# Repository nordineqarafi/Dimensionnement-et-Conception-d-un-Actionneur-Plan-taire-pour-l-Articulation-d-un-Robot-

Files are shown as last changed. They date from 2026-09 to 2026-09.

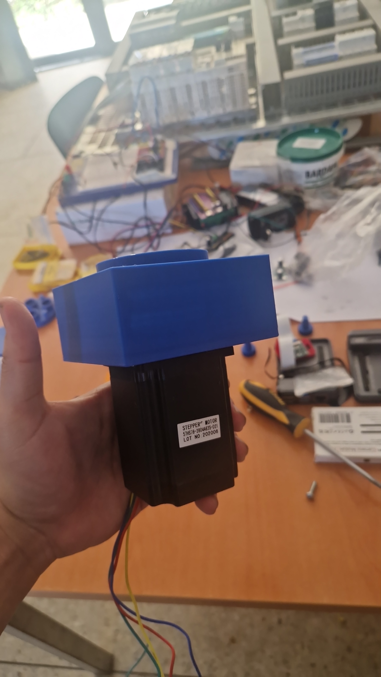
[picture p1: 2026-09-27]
1000091351.jpg

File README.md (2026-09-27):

# Dimensionnement et conception d’un actionneur planétaire pour un robot d’inspection TGV

**Noureddine Qarafi · Qassab Abderrahmane · Aymane El Haoudar**  
**ENSAM Meknès · Filière GEE-MCI · Année universitaire 2025/2026**

Projet de conception mécatronique consacré au **dimensionnement d’un actionneur planétaire** destiné aux articulations d’un bras robotisé d’inspection sous caisse de train à grande vitesse.

Le système étudié associe un **moteur pas à pas NEMA 23**, un **réducteur planétaire**, un **driver TB6600** et une **commande Arduino Mega 2560**. Le travail couvre le choix technologique, le dimensionnement mécanique du réducteur, les vérifications de résistance, l’étude de variantes d’intégration et la validation de la chaîne de commande.

## Contexte du projet

Le projet s’inscrit dans le développement du robot **InspecTrain**, destiné à automatiser l’inspection visuelle sous caisse des rames à grande vitesse.

Le robot doit évoluer dans une fosse d’inspection ferroviaire et orienter une caméra vers différentes zones du bogie, des essieux, du système de freinage, des canalisations et des câblages.

Le bras d’inspection comporte **trois degrés de liberté** :

- **Articulation 1 — rotation azimutale** : rotation panoramique du bras.
- **Articulation 2 — coude bas** : élévation du premier segment du bras.
- **Articulation 3 — coude haut** : orientation du segment terminal portant la caméra.

## Objectifs

- Étudier les contraintes mécaniques imposées aux articulations du bras.
- Comparer une motorisation **NEMA 23** à une solution **BLDC**.
- Dimensionner un réducteur planétaire compact.
- Vérifier les conditions géométriques d’assemblage des engrenages.
- Vérifier la résistance des dentures et des arbres.
- Étudier plusieurs variantes d’intégration mécanique.
- Mettre en place une chaîne de commande avec **Arduino Mega 2560 + TB6600 + NEMA 23**.
- Réaliser des essais de rotation et préparer l’évolution vers une commande de position plus avancée.

## Architecture générale

```mermaid
flowchart LR
    A[Arduino Mega 2560] -->|STEP / DIR / ENA| B[Driver TB6600]
    B -->|Courants de phase| C[Moteur NEMA 23]
    C --> D[Réducteur planétaire]
    D --> E[Articulation du bras]
    E --> F[Orientation de la caméra]
```

## Choix de la motorisation

Deux technologies ont été étudiées :

| Critère | NEMA 23 | BLDC |
| --- | --- | --- |
| Positionnement | Commande native par pas | Nécessite codeur et boucle fermée |
| Fonctionnement à basse vitesse | Adapté | Plus complexe |
| Couple de maintien | Élevé à l’arrêt | Nécessite une commande active |
| Électronique de commande | Simple | Plus complexe |
| Intégration avec réducteur planétaire | Très adaptée | Possible |
| Rendement à haute vitesse | Modéré | Élevé |

Pour cette application, le **NEMA 23** a été retenu principalement pour sa simplicité de commande, sa précision de positionnement, son comportement à basse vitesse et son intégration compacte avec un réducteur coaxial.

## Dimensionnement du réducteur planétaire

La configuration étudiée utilise :

| Paramètre | Valeur |
| --- | ---: |
| Nombre de dents du soleil `Z1` | 18 |
| Nombre de dents d’un satellite `Z2` | 18 |
| Nombre de dents de la couronne `Z3` | 54 |
| Nombre de satellites | 3 |
| Module | 1 mm |
| Couple moteur utilisé pour le calcul | 1,5 N·m |
| Rendement considéré | ≈ 0,9 |

La couronne est fixe, le soleil constitue l’entrée et le porte-satellites constitue la sortie.

### Rapport de réduction

Le rapport obtenu est :

```text
i = (Z1 + Z3) / Z1
  = (18 + 54) / 18
  = 4
```

La sortie tourne donc **quatre fois moins vite** que l’entrée.

Avec un couple moteur de `1,5 N·m` :

```text
Couple de sortie avec η = 0,9 : 5,4 N·m
Couple de sortie idéal :          6,0 N·m
```

## Vérifications géométriques

Les calculs permettent notamment de vérifier :

- la coaxialité entre soleil, satellites et couronne ;
- la condition d’assemblage des trois satellites ;
- l’absence d’interférence entre satellites ;
- la compatibilité des nombres de dents retenus.

Une attention particulière est portée à l’engrènement intérieur **satellite–couronne**, pour lequel le rapport met en évidence un risque d’interférence nécessitant un ajustement de la géométrie de denture.

## Vérification mécanique

### Dentures

L’effort tangentiel total transmis par le soleil est d’environ :

```text
Ft ≈ 166,7 N
```

Avec trois satellites, l’effort est réparti à environ :

```text
S ≈ 55,6 N par satellite
```

La vérification en flexion donne un module minimal inférieur à `1 mm`. Le **module m = 1 mm** retenu est donc validé pour cette vérification.

### Arbre du soleil — première variante

La première configuration imposait un arbre de diamètre `4 mm`.

La contrainte de torsion calculée est :

```text
τmax ≈ 119,4 MPa
```

Pour une contrainte admissible retenue de `60 MPa`, cette configuration **n’est pas validée** pour l’arbre du soleil.

### Axes des satellites

Pour les axes de satellites de `4 mm`, la contrainte calculée est d’environ :

```text
τmax ≈ 39,8 MPa
```

Le coefficient obtenu est d’environ :

```text
60 / 39,8 ≈ 1,51
```

Cette configuration reste donc acceptable pour les axes des satellites dans les hypothèses du rapport.

## Étude des variantes d’intégration

### Essai 1 — encombrement réduit

- Roulement avec alésage de `4 mm`.
- Arbre du soleil limité à `4 mm`.
- Solution compacte.
- Résistance insuffisante de l’arbre du soleil au couple étudié.

### Essai 2 — encombrement élargi

Le diamètre minimal de l’arbre est recalculé à partir du coefficient de sécurité recherché.

Pour un coefficient de sécurité `s = 3` :

```text
d ≥ 7,26 mm
```

Cette seconde approche libère davantage de place pour l’arbre et les roulements.

Un **carter carré** est également étudié afin de faciliter :

- l’intégration avec la bride du NEMA 23 ;
- la fixation mécanique ;
- l’usinage ou l’impression 3D ;
- l’intégration d’un roulement de diamètre plus important.

## Architecture de commande

La chaîne de commande repose sur trois niveaux :

1. **Arduino Mega 2560** — génération des signaux de commande.
2. **TB6600** — étage de puissance pour le moteur pas à pas.
3. **NEMA 23 + réducteur planétaire** — conversion électromécanique et transmission.

### Signaux utilisés

| Signal | Broche Arduino | Fonction |
| --- | --- | --- |
| STEP / PUL | `D30` | Impulsions de déplacement |
| DIR | `D32` | Sens de rotation |
| ENA | `D33` | Activation du driver |

## Paramètres du test moteur

Avec :

```text
delayTime = 800 µs
```

la fréquence d’impulsion obtenue est d’environ :

```text
fpulse ≈ 625 Hz
```

Pour un moteur de `200 pas/tour` :

```text
Nmoteur ≈ 187,5 tr/min
```

Avec le réducteur `4:1` :

```text
Nsortie ≈ 47 tr/min
```

Le programme de validation effectue des rotations dans les deux sens afin de vérifier le fonctionnement de l’ensemble **Arduino → TB6600 → NEMA 23 → réducteur**.

Le rapport présente également une extension possible vers un **profil de vitesse trapézoïdal** pour assurer une accélération et une décélération progressives.

## Résultats principaux

- Sélection du **NEMA 23** pour les articulations du bras.
- Dimensionnement d’un train planétaire compact.
- Rapport de réduction étudié : **4:1**.
- Couple de sortie estimé : **5,4 à 6,0 N·m**.
- Module d’engrenage `m = 1 mm` validé en flexion.
- Mise en évidence de la faiblesse d’un arbre du soleil de `4 mm`.
- Dimension d’arbre recommandée d’au moins **7,26 mm** pour un coefficient de sécurité de 3 dans les hypothèses étudiées.
- Validation de la commande bidirectionnelle du NEMA 23 avec **Arduino Mega + TB6600**.
- Étude d’une architecture mécanique plus robuste avec carter carré.

## Technologies et outils

`SolidWorks` · `Arduino Mega 2560` · `TB6600` · `NEMA 23` · `Réducteur planétaire` · `CAO mécanique` · `RDM` · `Dimensionnement d’engrenages` · `Mécatronique` · `Robotique`

## Compétences mises en œuvre

- Conception mécanique et mécatronique.
- Dimensionnement de trains planétaires.
- Calcul de rapports de réduction et de couples.
- Vérification mécanique en torsion et en flexion.
- Étude de variantes de conception.
- Intégration moteur–réducteur.
- Commande de moteur pas à pas.
- Programmation Arduino.
- Mise en service et diagnostic d’une chaîne électromécanique.

## Rapport

Le rapport complet contient le contexte du robot d’inspection, la conception du bras, la comparaison **NEMA 23 / BLDC**, les calculs du réducteur, les vérifications mécaniques, les essais d’intégration, l’architecture Arduino/TB6600 ainsi que le protocole de test.

```text
rapport_actionneur_planetaire.pdf
```

## Auteurs

- **Noureddine Qarafi**
- **Qassab Abderrahmane**
- **Aymane El Haoudar**

**Encadrant : Pr. Badr Bououlid Idrissi**  
**École Nationale Supérieure d’Arts et Métiers de Meknès — Université Moulay Ismaïl**

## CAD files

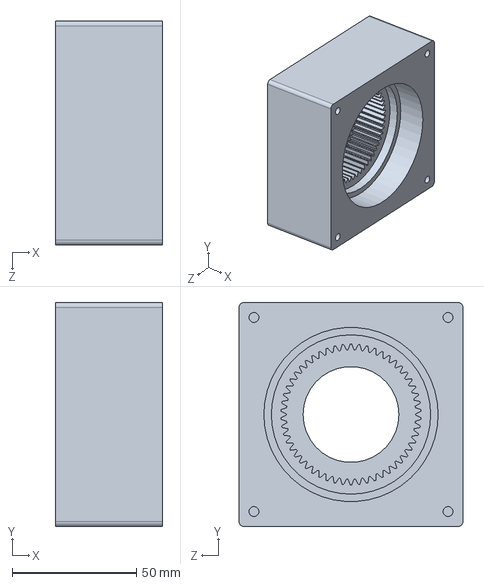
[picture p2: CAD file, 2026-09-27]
nema17/couronn_nema17.SLDPRT
43.0 x 90.0 x 90.0 mm

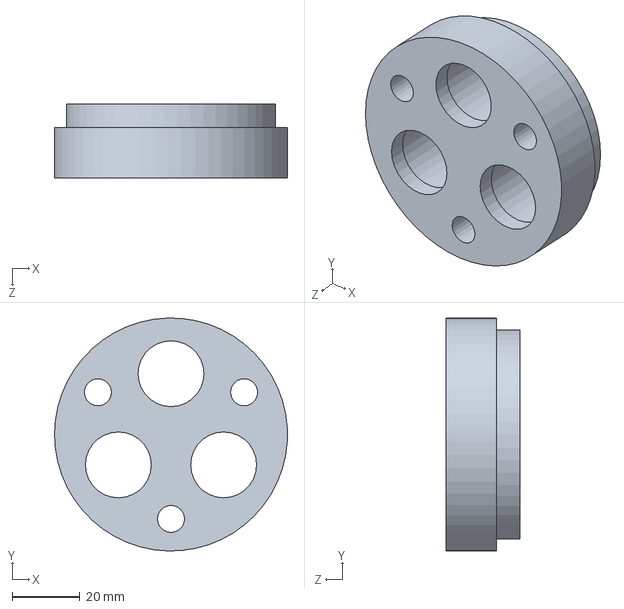
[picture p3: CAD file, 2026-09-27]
nema23/plateau.SLDPRT
69.0 x 69.0 x 22.0 mm

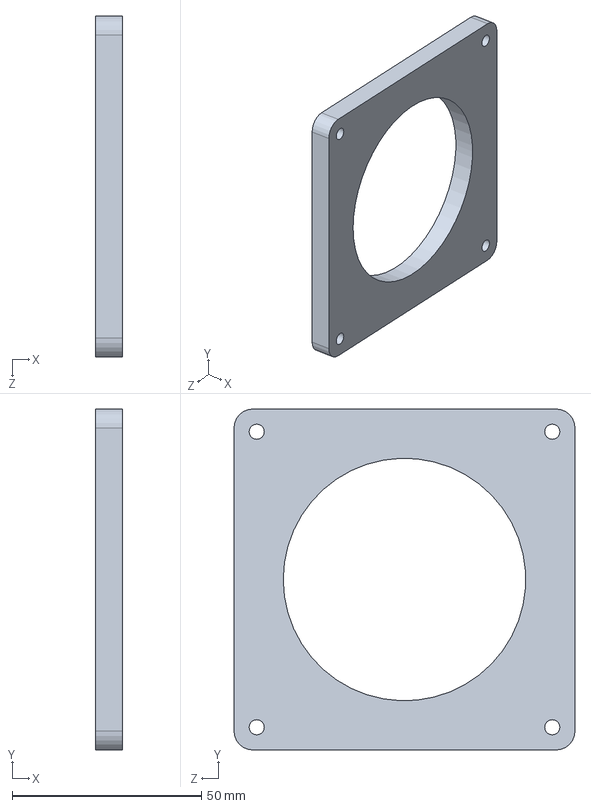
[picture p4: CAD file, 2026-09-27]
nema17/COUVERCLE.SLDPRT
7.00 x 90.0 x 90.0 mm

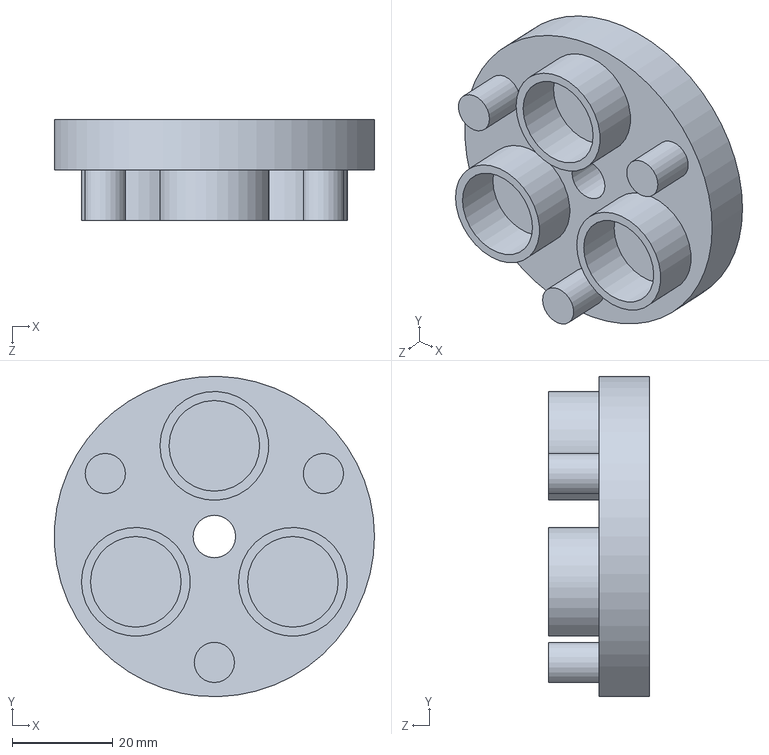
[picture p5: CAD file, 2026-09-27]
nema17/arret.SLDPRT
63.5 x 63.6 x 20.0 mm

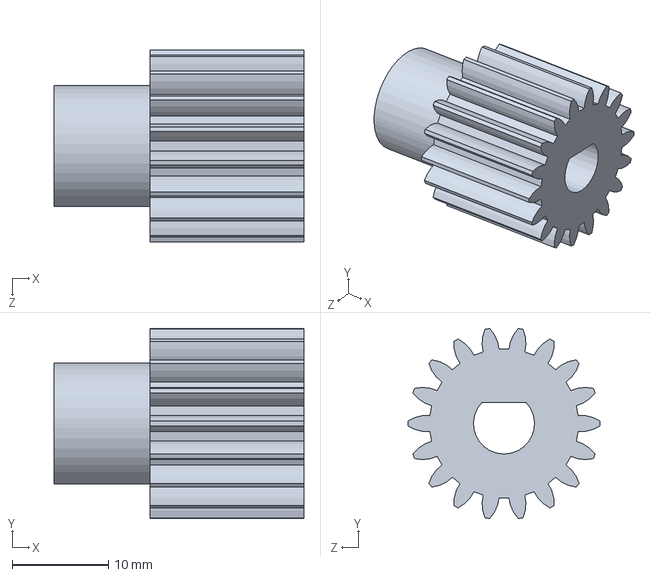
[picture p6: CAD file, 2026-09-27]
nema23/roue sun.SLDPRT
26.0 x 19.8 x 20.0 mm

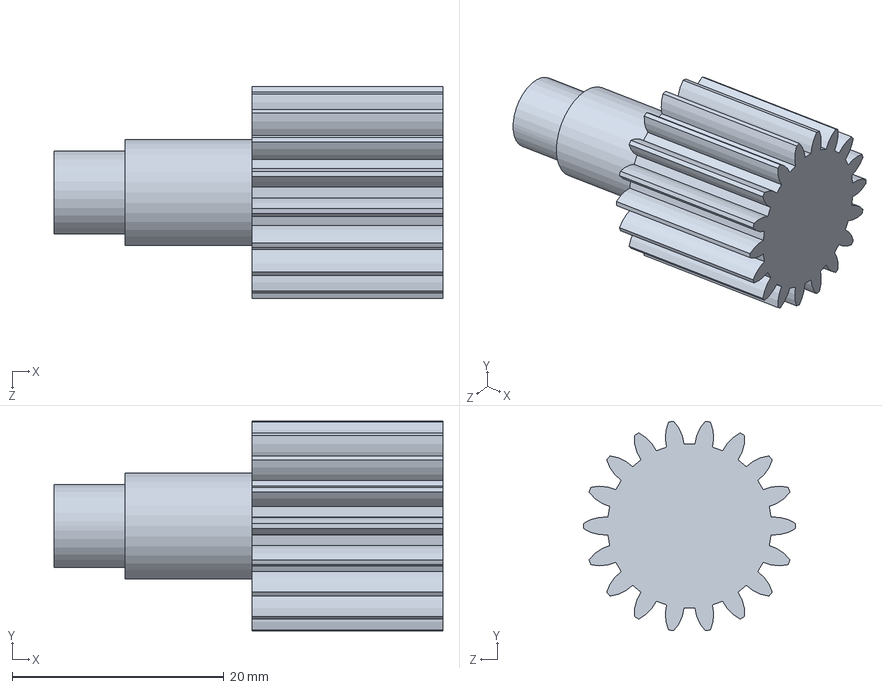
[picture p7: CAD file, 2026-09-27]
nema17/roue sateillite.SLDPRT
36.7 x 19.8 x 20.0 mm

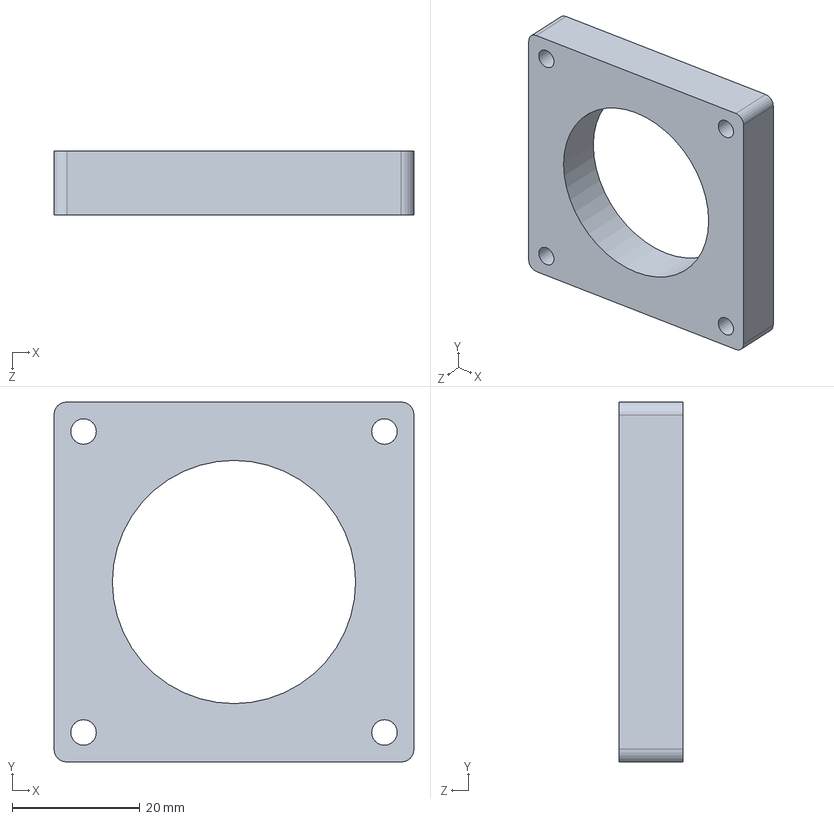
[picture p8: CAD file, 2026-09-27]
nema23/10mmnema23.SLDPRT
56.4 x 56.4 x 10.0 mm

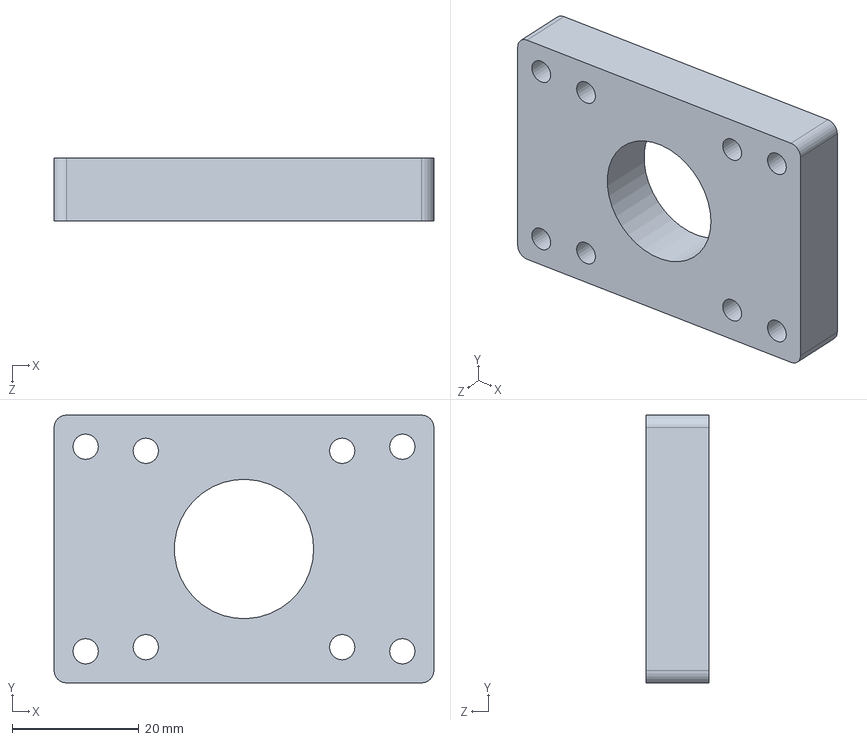
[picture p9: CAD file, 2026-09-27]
nema17/10mm.SLDPRT
60.0 x 42.3 x 10.0 mm

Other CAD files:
nema23/couronne.SLDPRT
nema17/roue_sun_nema17.SLDPRT
